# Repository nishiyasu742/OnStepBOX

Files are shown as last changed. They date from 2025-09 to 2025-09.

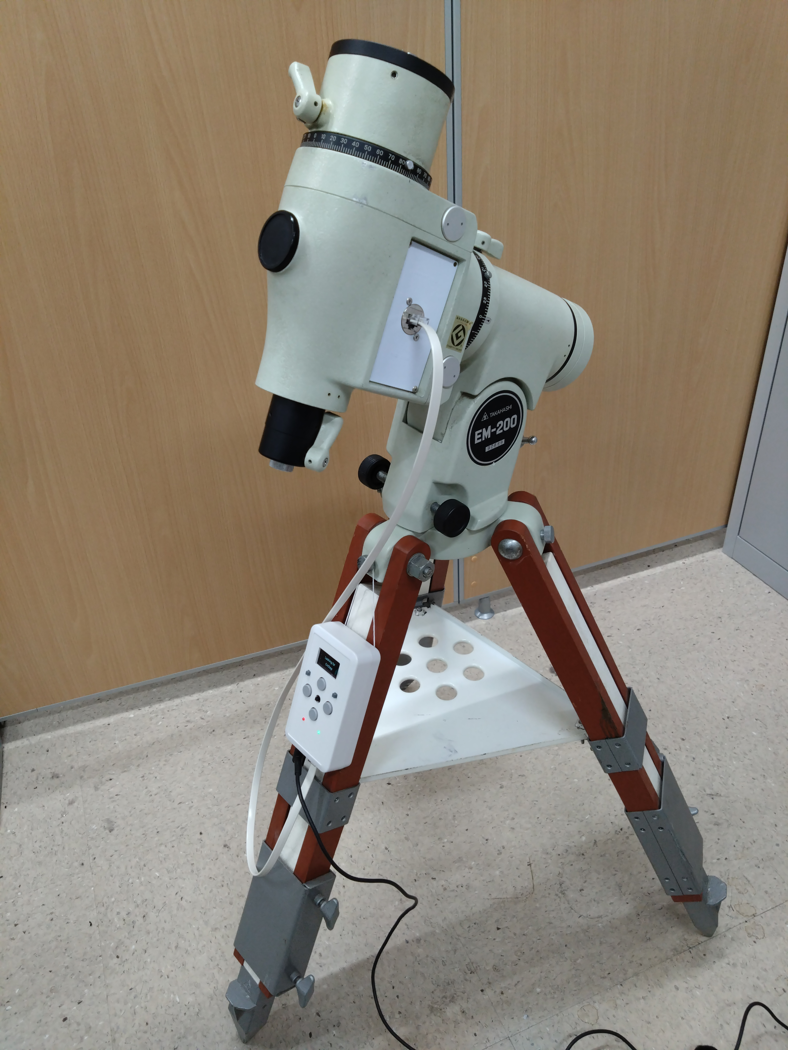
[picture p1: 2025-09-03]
１.JPG

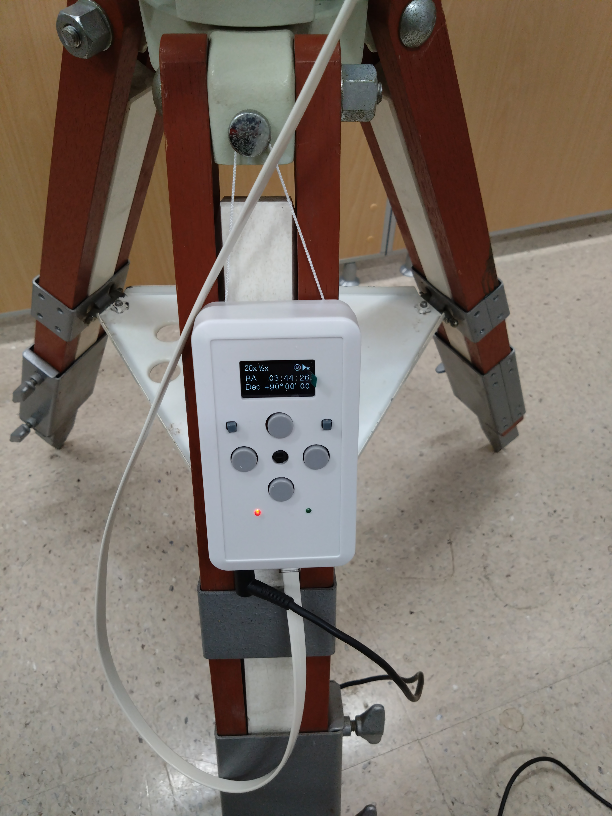
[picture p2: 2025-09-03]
２.JPG

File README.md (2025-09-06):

# OnStepBOX

OnStepBOX is a compact, integrated controller box that combines an OnStep-compatible Smart Hand Controller (SHC) and the main OnStep controller into a single unit.  
This project is based on the **OnStep MaxESP3 hardware design** and uses the **OnStep firmware (GPLv3 licensed)**.  

---

## Overview

- **Purpose**: Simplify telescope control by merging two devices (main OnStep controller + SHC) into one.  
- **Base design**: Derived from the [OnStep MaxESP3](https://onstep.groups.io/g/main/wiki/MaxESP3) hardware.  
- **Firmware**: Fully compatible with OnStep firmware (licensed under GPLv3).  
- **Use case**: Ideal for amateur astronomers who want a reliable, compact, and user-friendly OnStep system without carrying multiple devices.  

---

## Features

- Integrated SHC and OnStep controller in a single enclosure  
- Based on the proven **OnStep MaxESP3 circuit design**  
- Compatible with the official OnStep firmware (GPLv3)    
- Compact build using an off-the-shelf plastic enclosure (machined, not 3D-printed)  
- Designed for DIY assembly with widely available components  

---

## Photos

- Image captured using a Takahashi EM200 mount.  
  

- OnStepBOX's appearance  
  

- The bottom surface of OnStepBOX  
 

- Inside the OnStepBOX  
  

---

## Schematic & Pin Mapping

This project follows the **OnStep MaxESP3** pin mapping for firmware configuration.  
Be sure to select the correct board definition in OnStep when compiling.  

- Schematic:  
 OnStepBOX回路図

---

## Required Components

- ESP32 development board (ESP-32S recommended)  
- Stepper motor drivers (e.g., DRV8825, TMC5160)  
- Standard OnStep-compatible connectors and cables  
- Off-the-shelf plastic enclosure (Takachi LC135-H-N-W)  
- Miscellaneous components (buttons, display, etc.)  

---

## Assembly Instructions

- **Prepare the enclosure**  
  Purchase the specified case (Takachi LC135-H-N-W)  and machine openings for connectors, display, and buttons using the attached G-code with a CNC milling machine.

- **Prepare the PCB**  
  Send the attached Gerber files to a PCB manufacturer (e.g., Elecrow, JLCPCB) and place an order.

- **Assemble the PCB**  
  Purchase the required components and solder them to complete the PCB.

- **Flash the firmware**  
  - Download the latest OnStep firmware.  
  - Flash the first MPU following the MaxESP3 pin map.  
  - Flash the second MPU with the Smart Hand Controller firmware.  

- **Final checks**  
  - Verify motor wiring and operation.  
  - Test the SHC interface.  
  - Confirm alignment and control with the telescope mount.  
---

## License

This project is distributed under the **GNU General Public License v3 (GPLv3)**.  
Since it is derived from **OnStep hardware and firmware**, it must remain open source.  

- A full copy of the GPLv3 license text is included in the [LICENSE](LICENSE) file.  

---

## Acknowledgments

- Original [OnStep project](https://onstep.groups.io/g/main) by **Howard Dutton** and contributors  
- OnStep MaxESP3 hardware design (the base for this project)  
- Open-source astronomy community for valuable feedback and improvements  

---

— NEWEVI

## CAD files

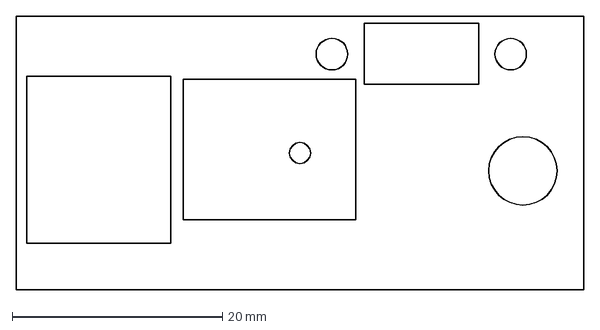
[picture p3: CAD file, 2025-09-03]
OnStepBOX Side.dxf
54.0 x 26.0 mm

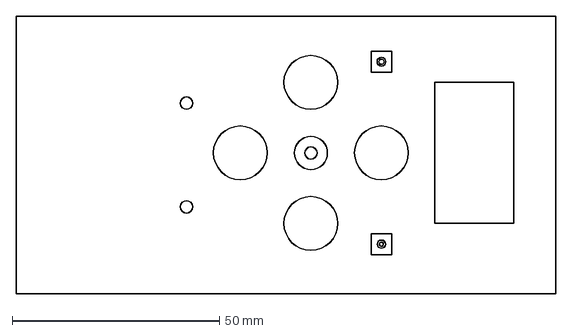
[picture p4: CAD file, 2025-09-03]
OnStepBOX Surface.dxf
130.0 x 67.0 mm

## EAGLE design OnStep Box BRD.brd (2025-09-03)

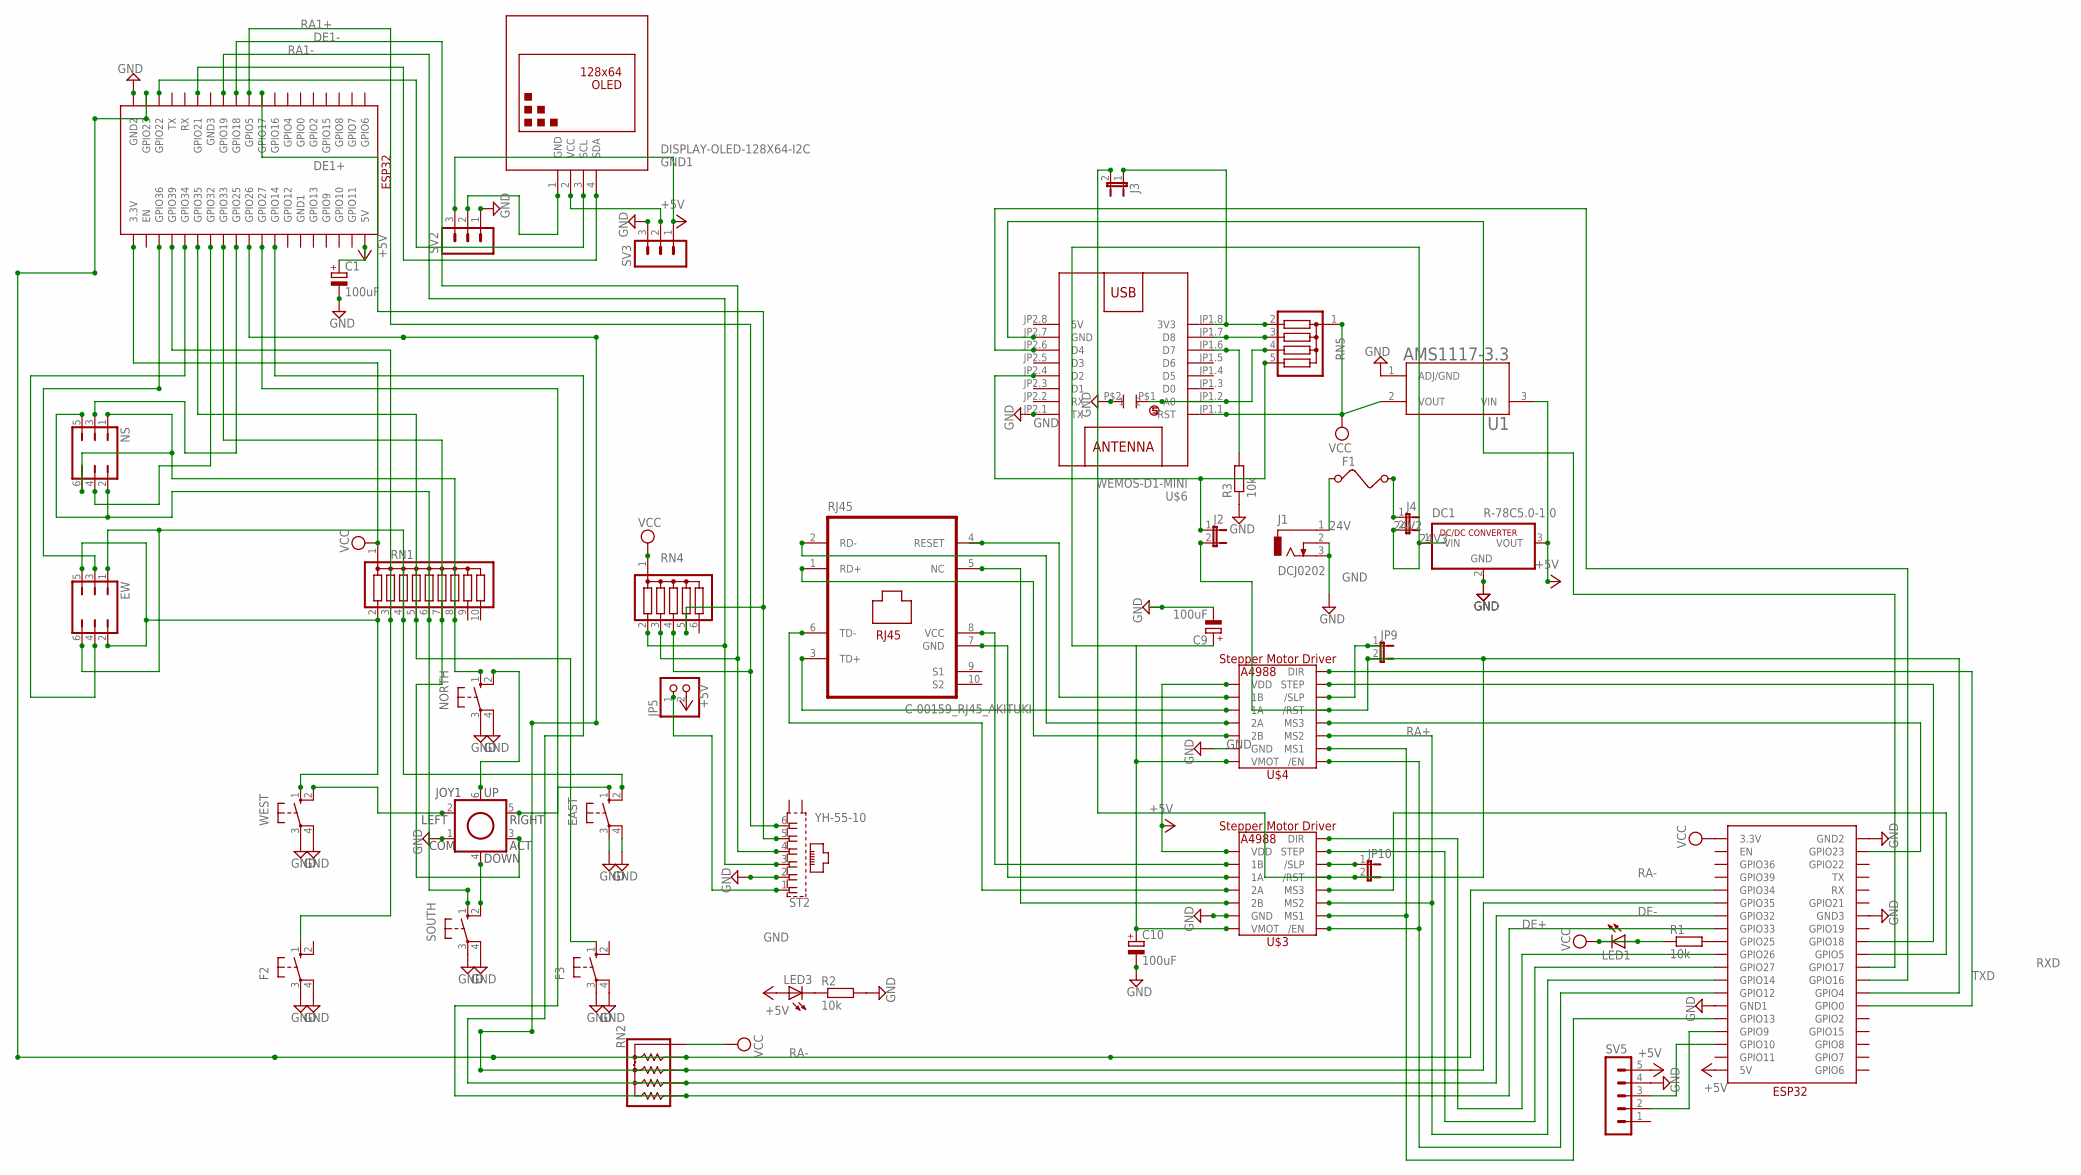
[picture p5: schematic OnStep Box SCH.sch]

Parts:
C1: 100uF; E2-4
C9, C10: 100uF; E2-5
CERAMIC_CAPACITOR1: CERAMIC_CAPACITOR
DC1: R-78C5.0-1.0; SIP3
EAST: 40-XX; B3F-40XX
EW: JP3Q
F1: FUSE
F2, F3: 10-XX; B3F-10XX
GND1: DISPLAY-OLED-128X64-I2C
J1: DCJ0202
J2, J3, J4: JP1E; JP1
JOY1: JOYSTICK
JP5: PINHD-1X2; 1X02
JP9, JP10: JP1E; JP1
LED1, LED3: LEDSFH480; SFH480
NORTH: 40-XX; B3F-40XX
NS: JP3Q
R1, R2, R3: 10k; 0204/5
RJ45: C-00159_RJ45_AKITUKI; PJ-J0
RN1: G09R; SIL10
RN2: 4605X; SIP5
RN4: G05R; SIL6
RN5: G04R; SIL5
SOUTH: 40-XX; B3F-40XX
ST2: YH-55-10
SV2, SV3: MA03-1
SV5: MA05-1
U1: AMS1117-3.3; SOT229P700X180-4N
U$1, U$7: ESP32
U$3, U$4: A4988_STEP
U$6: WEMOS-D1-MINI
WEST: 40-XX; B3F-40XX

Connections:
5V: U$6.JP2.8 (5V)
24V: F1.1, J1.1
24V2: F1.2, J4.1
24V3: C9.+, C10.+, DC1.1 (VIN), J4.2, U$3.VMOT, U$4.VMOT
+5V: C1.+, DC1.3 (VOUT), JP5.2, LED3.A, SV2.3, SV3.1, SV5.5, U1.3 (VIN), U$1.5V, U$3.VDD, U$4.VDD, U$7.5V
DE1+: RN4.5, ST2.5, U$7.GPIO17
DE1-: RN4.3, ST2.4, U$7.GPIO18
DE+: RN2.5, U$1.GPIO33, U$7.GPIO27
DE-: RN2.4, U$1.GPIO32, U$7.GPIO14
GND: C1.-, C9.-, C10.-, CERAMIC_CAPACITOR1.P$2 (2), DC1.2 (GND), EAST.3, EAST.4 (P1), F2.3, F2.4 (P1), F3.3, F3.4 (P1), J1.2, J1.3, JOY1.1 (COM), NORTH.3, NORTH.4 (P1), R2.2, R3.1, SOUTH.3, SOUTH.4 (P1), ST2.2, SV2.1, SV3.3, SV5.4, U1.1 (ADJ/GND), U$1.GND1, U$1.GND2, U$1.GND3, U$3.GND, U$3.GND2 (GND), U$4.GND, U$4.GND2 (GND), U$6.JP2.1 (TX), U$7.GND2, WEST.3, WEST.4 (P1)
unnamed: GND1.1 (GND), SV2.2
unnamed: LED3.K (C), R2.1
unnamed: R1.2, U$1.GPIO25
unnamed: SV5.3, U$1.GPIO10
unnamed: SV5.2, U$1.GPIO9
unnamed: U$1.GPIO12, U$3./EN, U$4./EN
unnamed: U$1.GPIO13, U$3.MS1, U$4.MS1
unnamed: U$1.GPIO14, U$3.MS2, U$4.MS2
unnamed: JP10.1, U$3./SLP
unnamed: U$1.GPIO26, U$3.DIR
unnamed: U$1.GPIO27, U$3.STEP
unnamed: U$1.GPIO23, U$4.MS3
unnamed: J2.2, J3.2, JP9.1, JP9.2, JP10.2, U$1.GPIO4, U$3./RST, U$4./RST, U$4./SLP
unnamed: J3.1, RN5.2, U$6.JP1.8 (3V3)
unnamed: U$1.GPIO18, U$4.STEP
unnamed: RJ45.4 (RESET), U$4.1B
unnamed: RJ45.5 (NC), U$3.2B
unnamed: RJ45.8 (VCC), U$3.1B
unnamed: GND1.2 (VCC), SV3.2
unnamed: RJ45.7 (GND), U$3.1A
unnamed: RN5.3, U$6.JP1.7 (D8)
unnamed: RJ45.6 (TD-), U$3.2A
unnamed: U$1.GPIO5, U$3.MS3
unnamed: R3.2, U$6.JP1.6 (D7)
unnamed: CERAMIC_CAPACITOR1.P$1 (1), RN5.4, U$6.JP1.2 (A0)
unnamed: U$1.GPIO0, U$4.DIR
unnamed: RJ45.2 (RD-), U$4.2A
unnamed: RJ45.1 (RD+), U$4.2B
unnamed: J2.1, RN5.5, U$6.JP2.4 (D2)
unnamed: RJ45.3 (TD+), U$4.1A
unnamed: GND1.3 (SCL), U$7.GPIO22
unnamed: GND1.4 (SDA), U$7.GPIO21
unnamed: EW.3, U$7.GPIO36
unnamed: EAST.2 (S1), EW.1, EW.6, RN1.4
unnamed: NS.2, NS.5, RN1.6, SOUTH.1 (S)
unnamed: JOY1.2 (LEFT), WEST.2 (S1)
unnamed: EAST.1 (S), JOY1.5 (RIGHT)
unnamed: NORTH.1 (S), NS.1, NS.6, RN1.8
unnamed: JP5.1, ST2.1
unnamed: F2.1 (S), RN1.3, U$7.GPIO39
unnamed: F3.1 (S), RN1.5, U$7.GPIO35
unnamed: NS.3, U$7.GPIO25
unnamed: NS.4, U$7.GPIO32
unnamed: EW.2, EW.5, RN1.2, WEST.1 (S)
unnamed: EW.4, U$7.GPIO34
unnamed: JOY1.6 (UP), NORTH.2 (S1)
unnamed: JOY1.4 (DOWN), SOUTH.2 (S1)
unnamed: JOY1.3 (ACT), RN1.7, U$7.GPIO33
RA1+: RN4.4, ST2.6, U$7.GPIO5
RA1-: RN4.2, ST2.3, U$7.GPIO19
RA+: RN2.3, U$1.GPIO35, U$7.GPIO26
RA-: RN2.2, U$1.GPIO34, U$7.GPIO23
RXD: U$1.GPIO17, U$6.JP2.7 (GND)
TXD: U$1.GPIO16, U$6.JP2.6 (D4)
VCC: LED1.A, LED1.K (C), R1.1, RN1.1, RN2.1, RN4.1, RN5.1, U1.2 (VOUT), U$1.3.3V, U$6.JP1.1 (RST), U$7.3.3V

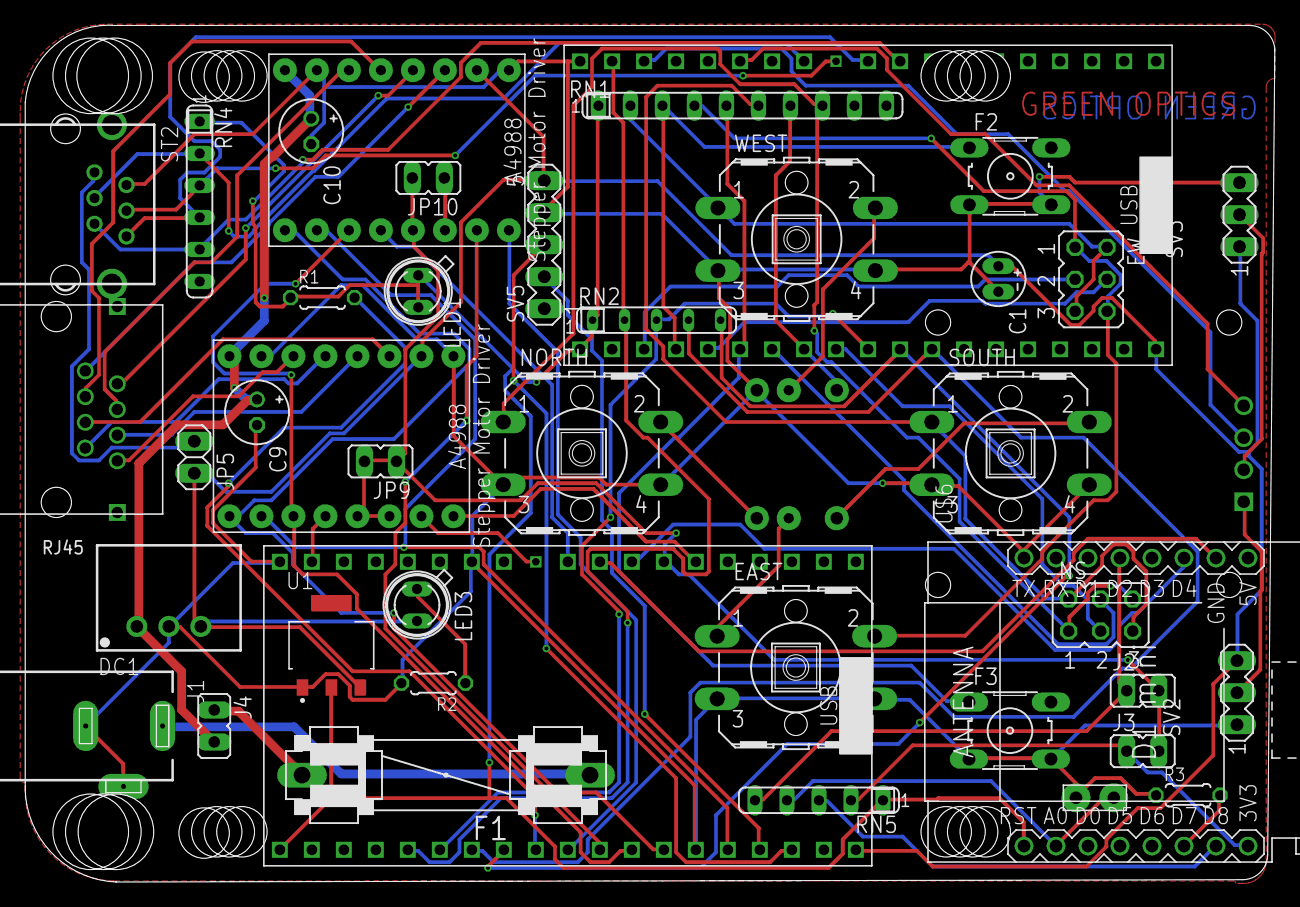
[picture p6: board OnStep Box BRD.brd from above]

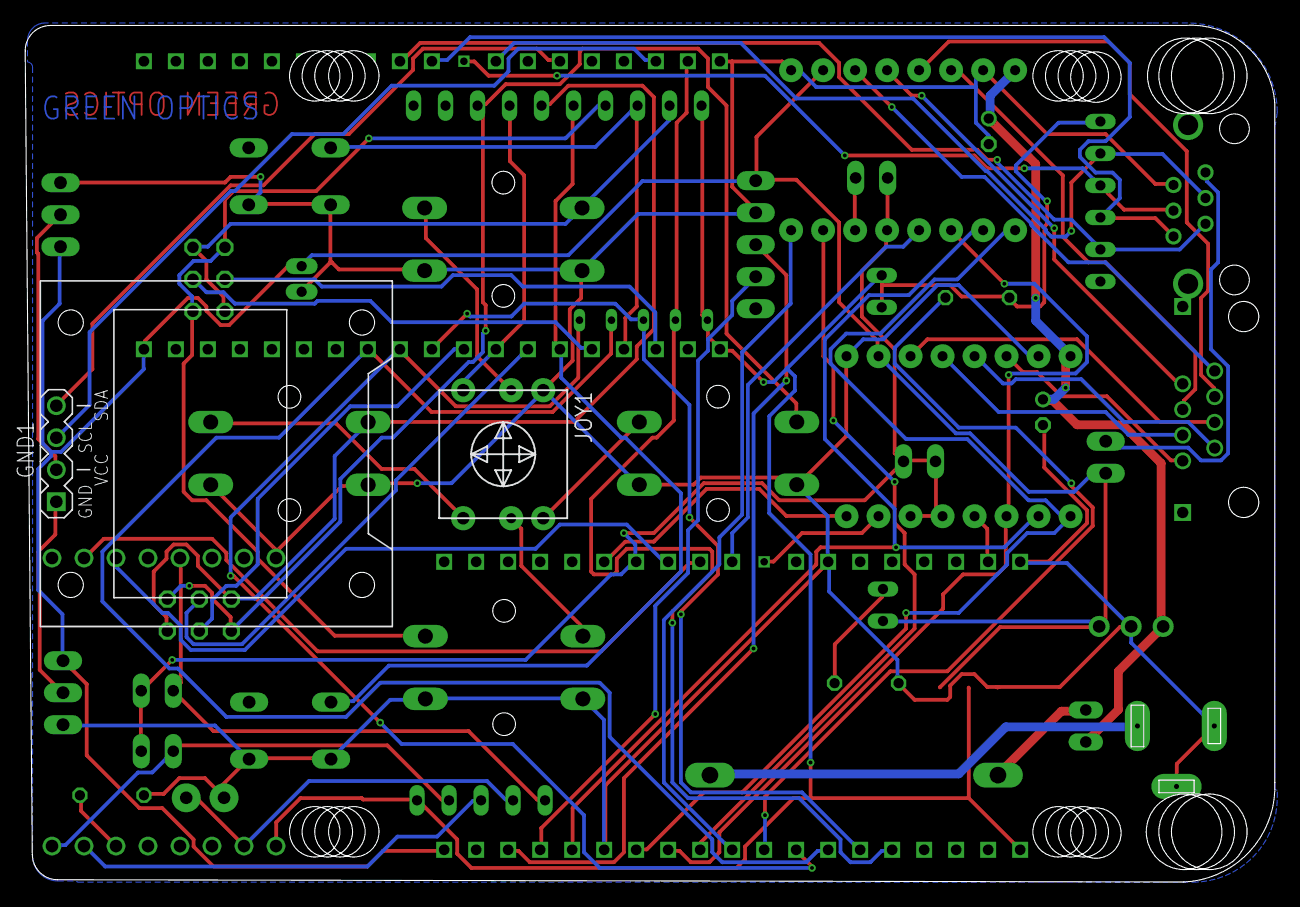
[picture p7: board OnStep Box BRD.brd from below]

Board: 2 copper layers, 99.2 x 68.0 mm, 43 parts (2 on the bottom side), 64 nets.

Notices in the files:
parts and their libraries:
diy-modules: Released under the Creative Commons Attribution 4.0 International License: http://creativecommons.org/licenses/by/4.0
